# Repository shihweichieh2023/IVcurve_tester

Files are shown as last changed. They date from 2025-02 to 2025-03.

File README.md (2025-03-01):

# I-V Curve Analyzer

A versatile measurement tool for characterizing low-power energy sources, with a focus on Dye-Sensitized Solar Cells (DSSC) and other experimental photovoltaic devices. This open hardware project uses an ESP32-S3 Mini to provide accurate I-V curve measurements and real-time Maximum Power Point tracking.

Originally developed for DIYbio and Hackteria workshops, this analyzer is perfect for:

- Testing Dye-Sensitized Solar Cells (DSSC) with natural dyes
- Characterizing small commercial solar cells
- Evaluating thermoelectric generators (TEGs)
- Educational demonstrations of photovoltaic principles
- Rapid prototyping of new energy harvesting devices

The logarithmic resistor array and optional MOSFET configuration allow measurements across a wide range of power outputs, from µW to mW scale, making it ideal for testing experimental and low-power energy sources.

## Features

- Real-time I-V curve measurement
- Maximum Power Point (MPP) tracking
- ADC (ADS1115) for precise voltage measurements
- OLED display with live readings
- E-ink display for persistent measurements
- Logarithmic resistor array for wide measurement range
- Optional MOSFET for low-resistance measurements
- Optional: Built-in voltage divider for measuring higher voltage sources (>3.3V)

## Button Control
The device features a single button for measurement control:

- OLED display: continously provides real-time measurement data
- Single press: Initiates a new I-V curve measurement to be displayed on the E-ink display and sent to the serial.

## Example I-V Curve
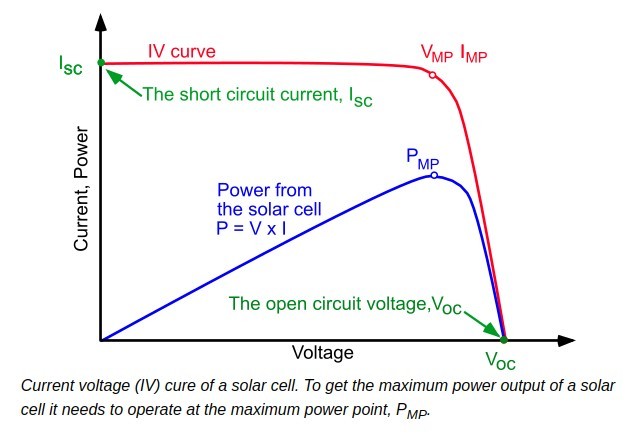
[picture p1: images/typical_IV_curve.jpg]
Typical solar cell I-V curve showing short circuit current (Isc), open circuit voltage (Voc), and Maximum Power Point (MPP)


The analyzer measures both the I-V characteristics (blue curve) and power output (red curve) by sweeping through different load resistances. The Maximum Power Point (MPP) represents the optimal operating point where the product of voltage and current yields the highest power output.

## E-Ink Display Interface
The analyzer features a 2.9" tri-color (black, white, and red) e-ink display (Adafruit IL0373) for persistent measurement visualization. The e-ink display offers:

- High contrast, daylight-readable display
- Persistent display of measurements even when powered off
- 296x128 pixel resolution
- Low power consumption
- E-ink display: Shows the I-V curve with key measurements (Voc, Isc, MPP) 
- The previous measurement is displayed too in lower contrast to compare

The e-ink display provides a persistent view of your latest results that remains visible even when the device is powered off.

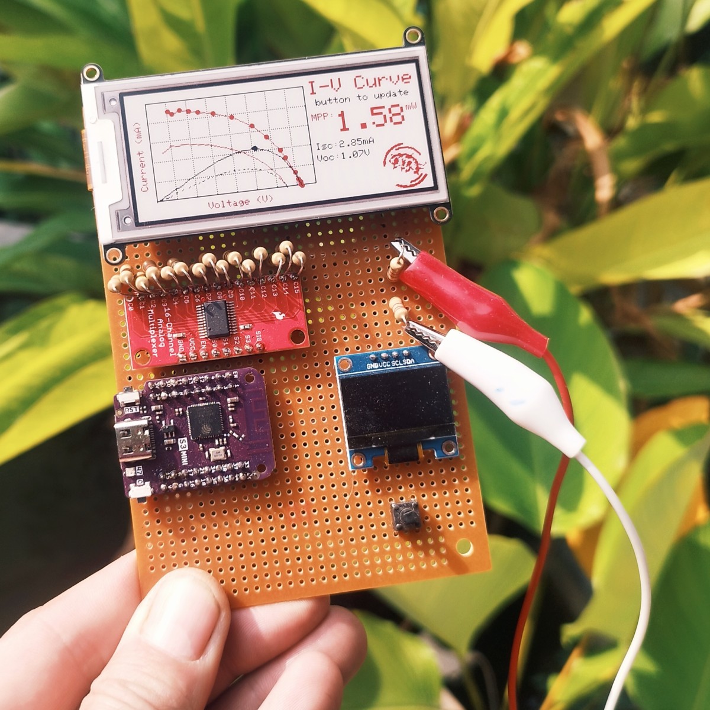
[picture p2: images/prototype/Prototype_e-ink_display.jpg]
E-ink display showing I-V curve measurements

*The e-ink display shows the current measurement in dark contrast while the previous measurement is shown in lighter contrast for easy comparison.*

## Web Interface
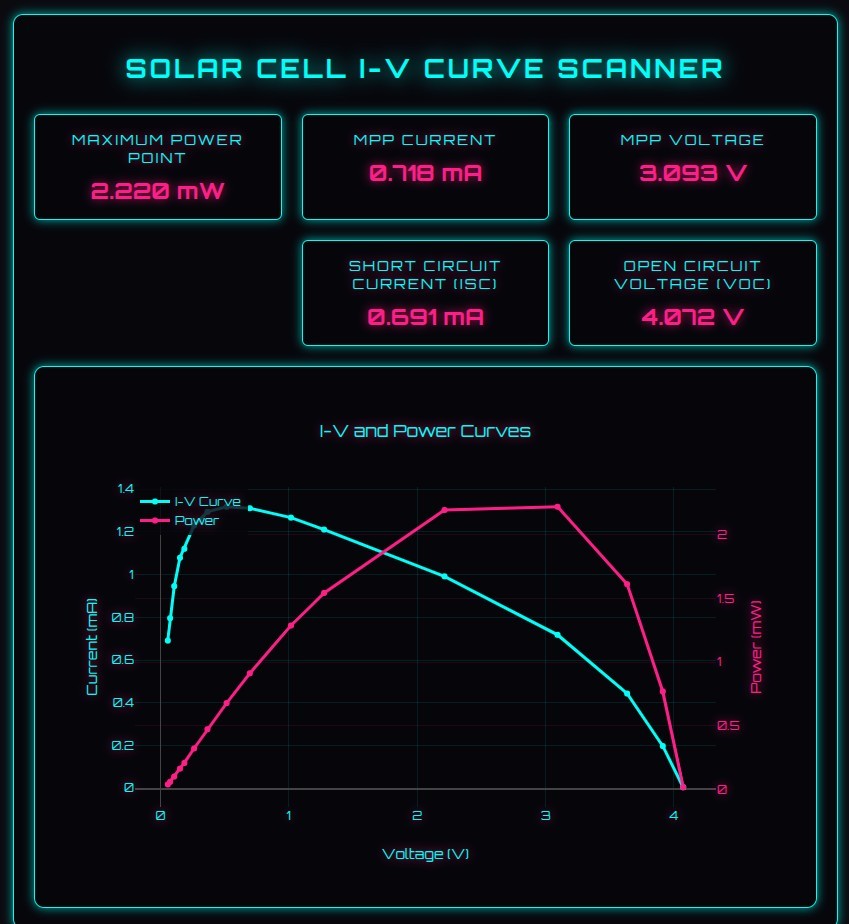
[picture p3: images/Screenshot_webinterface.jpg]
Web interface showing real-time I-V curve and power measurements


The web interface provides real-time visualization of measurements, displaying both the I-V curve (blue) and power curve (pink). Key measurements like Maximum Power Point (MPP), Short Circuit Current (Isc), and Open Circuit Voltage (Voc) are shown in an easy-to-read card layout.

## Hardware Overview
```ascii
+-------------+     +-----------+     +--------------+
|  Solar      |     | ADS1115   |     |  ESP32-S3    |
|  Cell       |---->| ADC (I2C) |---->|    Mini      |
| (DUT)       |     |           |     | (I2C Master) |
+-------------+     +-----------+     +--------------+
       |                                    ^
       |                                    |
       |                                    |
       |                                    |
       |           +---------+              |
       +---------->| MOSFET  |              |
       |           | Circuit |              |
       |           +---------+        +---------------+
       |                |            | UI Controls   |
       |                v            | OLED, Pots,   |
       |               GND           | Button,E-ink  |
       |                             +---------------+
       |
       |
       |            +----------+     +-----------+
       +----------->| Resistor |     |    MUX    |
                    |  Array   |---->|  ADG706   |
                    | (R1-R16) |     | or 4067   |
                    +----------+     +-----------+
                                          |
                                          |
                                          v
                                         GND
```

## Key Components

- ESP32-S3 
- ADG705 16-channel multiplexer
   - or lower precision: CD74HC4067 16-channel multiplexer
- SSD1306 OLED display
- 16 precision resistors (15Ω - 20kΩ)
- MOSFET for low-resistance measurements
- ADS1115 ADC for precision Analog Voltage measurements

## Technical Notes
### Low internal resistance with ADG706 Multiplexer
To be able to measure the currents at high load (low voltages), which completes the curve to the end, a high quality multiplexer is needed, with very low internal resistance. This is the reason why ADG706 was chosen over the CD74HC4067.

#### Resistance Measurement Accuracy with 4067
The CD74HC4067 multiplexer has a significant internal ON resistance (RON) of approximately 70Ω that affects measurements. Rather than compensating for this in software, we've directly measured each resistor through the MUX circuit. The resistor values listed in the code (83Ω - 10.3kΩ) already include this MUX internal resistance, ensuring accurate current calculations without additional compensation.

For example:
 
- A 13Ω resistor + ~70Ω MUX RON = 83Ω actual measured value
- This combined resistance is what's stored in the code
- No additional software compensation needed
- Measurements remain accurate across the full range

### Sensitivity of the ESP32 internal ADC
The ESP32 is known for quite a shitty ADC, non-linear in the middle range, with a very slow slope near the ends. This can cause significant issues with accurate voltage measurements, especially at low voltages.

### Use external ADC, such as ADS1115
Solves the issue.

## Getting Started
1. Clone this repository
2. Install PlatformIO
3. Connect hardware according to [hardware/HARDWARE.md](hardware/HARDWARE.md)
4. Build and upload using PlatformIO

## License
MIT License - See [LICENSE](LICENSE) file

## More Information
See [hardware/HARDWARE.md](hardware/HARDWARE.md) for detailed wiring and setup instructions.

## PCB Design and Prototypes
The project includes a custom PCB design for a MUX ADG706 for more reliable measurements and compact implementation. Design files and documentation can be found in:
 
- Hardware documentation: [`hardware/HARDWARE.md`](hardware/HARDWARE.md)
- PCB design files: [`hardware/MUX-ADG706/`](hardware/MUX-ADG706/)
- PCB renders: [`images/pcb/`](images/pcb/)
- Prototype photos: [`images/prototype/`](images/prototype/)

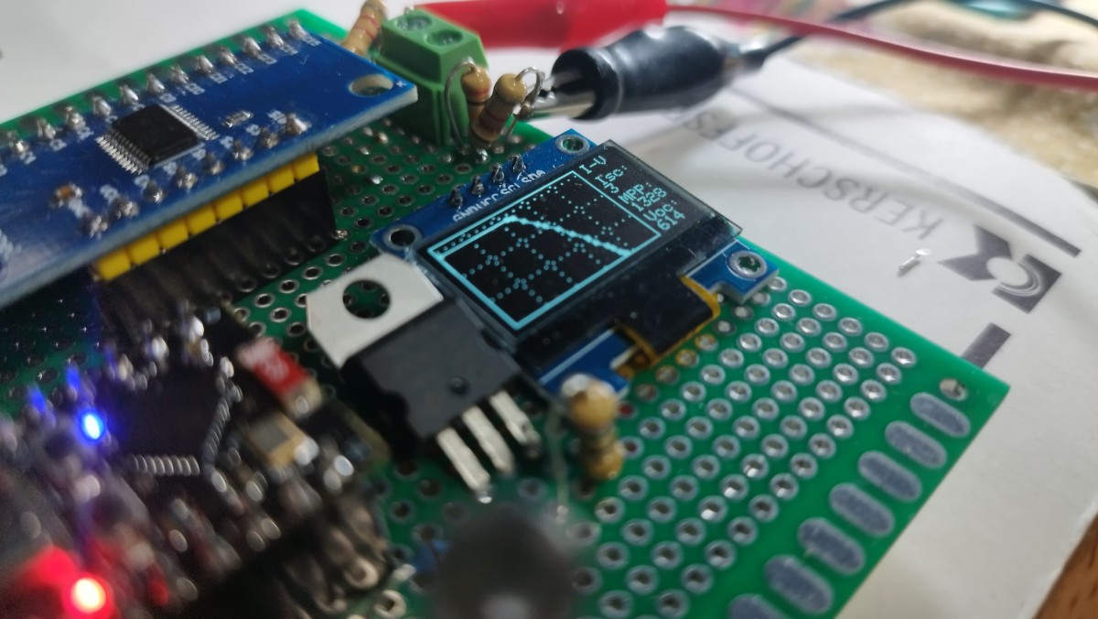
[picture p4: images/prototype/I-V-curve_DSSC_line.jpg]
Prototype measuring DSSC in line

*Close-up view of the analyzer displaying real-time measurements on the OLED screen. The device shows voltage, current, and power readings while performing I-V curve analysis.*

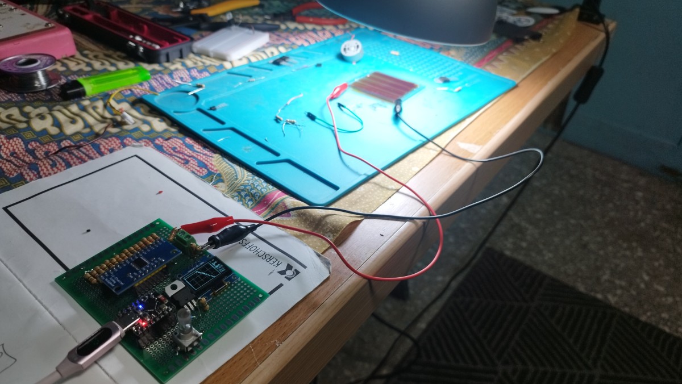
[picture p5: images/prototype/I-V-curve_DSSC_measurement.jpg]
Prototype during DSSC measurement

*First prototype of the I-V Curve Analyzer testing a series of Dye-Sensitized Solar Cells (DSSC). The compact design allows for easy in-line measurements during workshops and experiments.*

### Project Files
The KiCad project (`MUX-ADG706/`) contains:

- [`MUX-ADG706_v2.kicad_sch`](MUX-ADG706/MUX-ADG706_v2.kicad_sch) - Complete circuit schematic
- [`MUX-ADG706_v2.kicad_pcb`](MUX-ADG706/MUX-ADG706_v2.kicad_pcb) - PCB layout design
- [`gerber_MUX-ADG706_v2.zip`](MUX-ADG706/gerber_MUX-ADG706_v2.zip) - Gerber files for PCB manufacturing

## Credits
Code and hardware design by Marc Dusseiller (@dusjagr), with assistance from the Windsurf AI coding assistant. This collaboration demonstrates how AI tools can enhance open hardware development while maintaining human creativity and expertise at the core of the project.

## References
- I-V curve image from [PVEducation.org](https://www.pveducation.org/pvcdrom/solar-cell-operation/iv-curve)

## Future Improvements
Future development plans for the I-V Curve Analyzer include:

1. DONE **Enhanced Multiplexer**: Replace the current multiplexer with ADG706 for lower internal resistance, improving measurement accuracy especially in the low-resistance range.

2. ONGOING **IoT Integration**: Utilize the ESP32's WiFi capabilities to upload measurements to an IoT cloud service for:
   - Remote monitoring and data logging
   - Long-term performance analysis
   - Data sharing and collaboration

3. **On-Board Storage**: Implement measurement storage and numbering on the chip for:
   - Offline data collection
   - Sequential measurement tracking
   - Later retrieval and analysis

These improvements will enhance the device's functionality, usability, and data management capabilities while maintaining its core purpose as an accessible tool for energy harvesting research and education.

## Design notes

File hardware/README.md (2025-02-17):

# Hardware Design Files

This directory contains the hardware design files for the I-V Curve Analyzer project, including detailed assembly instructions and PCB design files.

E-ink display showing I-V curve measurements
*The e-ink display shows the current measurement in dark contrast while the previous measurement is shown in lighter contrast for easy comparison.*

## Directory Structure

- [`HARDWARE.md`](HARDWARE.md) - Detailed assembly instructions and wiring guide
- [`MUX-ADG706/`](MUX-ADG706/) - KiCad project files for the PCB design of the MUX

## PCB Design Overview

The PCB design is implemented in KiCad and features several key improvements over the prototype version:

### Multiplexer Upgrade
The main improvement is the replacement of the CD74HC4067 with the ADG706BRUZ-REEL7 multiplexer:

- Significantly lower ON resistance (~2.5Ω vs 70Ω in the CD74HC4067)
- Better channel-to-channel matching for more consistent measurements
- 28-pin SOP package for compact board layout

### Project Files
The KiCad project (`MUX-ADG706/`) contains:

- [`MUX-ADG706.kicad_sch`](MUX-ADG706/MUX-ADG706.kicad_sch) - Complete circuit schematic
- [`MUX-ADG706.kicad_pcb`](MUX-ADG706/MUX-ADG706.kicad_pcb) - PCB layout design
- [`gerber_MUX-ADG706.zip`](MUX-ADG706/gerber_MUX-ADG706.zip) - Gerber files for PCB manufacturing

### Component Library
The [`ad706/`](MUX-ADG706/ad706/) directory contains all necessary files for the ADG706 multiplexer:

- [`ADG706BRUZ-REEL7.kicad_sym`](MUX-ADG706/ad706/ADG706BRUZ-REEL7.kicad_sym) - KiCad symbol file
- [`SOP65P640X120-28N.kicad_mod`](MUX-ADG706/ad706/SOP65P640X120-28N.kicad_mod) - Footprint for the 28-pin SOP package
- [`ADG706BRUZ-REEL7.step`](MUX-ADG706/ad706/ADG706BRUZ-REEL7.step) - 3D model for visualization

## Design Goals

1. Improve measurement accuracy through lower multiplexer resistance
2. Maintain compact form factor
3. Ensure reliable connections for workshop use
4. Enable precise I-V curve measurements for solar cells and other low-power sources
5. Provide persistent measurement display through e-ink technology

## Display System

The device features a dual-display system:
- **OLED Display**: For real-time measurement data and device status
- **E-ink Display (2.9" Adafruit IL0373)**: For persistent measurement visualization
  - Shows current and previous I-V curves for comparison
  - Maintains display even when powered off
  - High contrast for outdoor readability

## Future Considerations

- Consider adding test points for easier debugging
- Evaluate thermal considerations for continuous operation
- Explore data logging capabilities for long-term studies

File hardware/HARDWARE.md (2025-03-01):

# I-V Curve Analyzer Hardware Documentation
=================================

## Overview
This I-V curve analyzer is designed for characterizing low-power energy sources using either an ESP32-S3 Mini or ESP32-C3 Super Mini board. It uses a multiplexer (CD74HC4067, with planned upgrade to ADG706) to switch between different load resistors and can optionally use a MOSFET for additional low-resistance measurements. A voltage divider is implemented to ensure the input voltage stays within the ESP32's ADC range (0-3.3V), allowing measurement of higher voltage sources while maintaining accuracy.

## Supported Hardware
The firmware supports two board configurations:
1. ESP32-S3 Mini (default)
2. ESP32-C3 Super Mini

To select your board, edit the `include/board_config.h` file and uncomment the appropriate board definition.

## Block Diagram
```ascii
+-------------+     +-----------+     +--------------+
|  Solar      |     | ADS1115   |     |  ESP32-S3    |
|  Cell       |---->| ADC (I2C) |---->|    Mini      |
| (DUT)       |     |           |     | (I2C Master) |
+-------------+     +-----------+     +--------------+
       |                                    ^
       |                                    |
       |                                    |
       |                                    |
       |           +---------+              |
       +---------->| MOSFET  |              |
       |           | Circuit |              |
       |           +---------+        +---------------+
       |                |            | UI Controls   |
       |                v            | OLED, Pots,   |
       |               GND           | Button,E-ink  |
       |                             +---------------+
       |
       |
       |            +----------+     +-----------+
       +----------->| Resistor |     |    MUX    |
                    |  Array   |---->|  ADG706   |
                    | (R1-R16) |     | or 4067   |
                    +----------+     +-----------+
                                          |
                                          |
                                          v
                                         GND
```

## Pin Assignments

### ESP32-S3 Mini
```markdown
# MUX Control
PIN_MUX_S0  (2)  -> MUX control pin S0
PIN_MUX_S1  (6)  -> MUX control pin S1
PIN_MUX_S2  (4)  -> MUX control pin S2
PIN_MUX_S3  (5)  -> MUX control pin S3

# Analog & Digital IO
PIN_SIG     (1)  -> ADC input for voltage measurement
PIN_POT_Y   (16) -> ADC input for Y-axis scaling
PIN_POT_X   (18) -> ADC input for X-axis scaling
PIN_BUTTON  (35) -> Digital input for mode button
PIN_TPI     (10) -> MOSFET control pin

# I2C Interface (OLED & ADS1115)
SDA_PIN     (8)  -> I2C Data
SCL_PIN     (9)  -> I2C Clock

# E-ink Display (SPI)
EPD_DC      (38) -> E-ink DC
EPD_CS      (37) -> E-ink CS
SRAM_CS     (33) -> SRAM CS
EPD_RESET   (10) -> E-ink Reset
SCLK        (12) -> SPI Clock
MISO        (13) -> SPI MISO
MOSI        (11) -> SPI MOSI
```

### ESP32-C3 Super Mini
```markdown
# MUX Control
PIN_MUX_S0  (21) -> MUX control pin S0
PIN_MUX_S1  (10) -> MUX control pin S1
PIN_MUX_S2  (2)  -> MUX control pin S2
PIN_MUX_S3  (1)  -> MUX control pin S3

# Analog & Digital IO
PIN_SIG     (0)  -> ADC input for voltage measurement
PIN_POT_Y   (4)  -> ADC input for Y-axis scaling
PIN_POT_X   (3)  -> ADC input for X-axis scaling
PIN_BUTTON  (7)  -> Digital input for mode button
PIN_TPI     (20) -> MOSFET control pin

# I2C Interface (OLED & ADS1115)
SDA_PIN     (8)  -> I2C Data
SCL_PIN     (9)  -> I2C Clock

# E-ink Display (SPI)
EPD_DC      (5)  -> E-ink DC
EPD_CS      (6)  -> E-ink CS
SRAM_CS     (9)  -> SRAM CS
SCLK        (8)  -> SPI Clock
MISO        (4)  -> SPI MISO
MOSI        (3)  -> SPI MOSI
```

## Components List

- ESP32-S3 Mini development board
- ADG705 16-channel multiplexer
   - or lower precision: CD74HC4067 16-channel multiplexer
- SSD1306 OLED display (128x64)
- Adafruit 2.9" Tri-Color eInk Display FeatherWing (IL0373)
- 16 precision resistors for measurement array
- ADS1115 analog-to-digital converter
- MOSFET circuit for low-resistance measurements
- Push button for measurement control
- Various connectors and headers

## Display Connections

### OLED Display (SSD1306)
- VCC → 3.3V
- GND → GND
- SCL → GPIO22
- SDA → GPIO21

### E-ink Display (IL0373)
- VIN → 3.3V
- GND → GND
- SCK → GPIO36
- MOSI → GPIO35
- DC → GPIO37
- CS → GPIO38
- RST → GPIO39
- BUSY → GPIO40

## Detailed Connections
### CD74HC4067 Multiplexer
```ascii
      +-----U-----+
CH7   |1  []   24| VCC
CH6   |2       23| CH8
CH5   |3       22| CH9
CH4   |4       21| CH10
CH3   |5       20| CH11
CH2   |6       19| CH12
CH1   |7       18| CH13
CH0   |8       17| CH14
COM   |9       16| CH15
S0    |10      15| EN
S1    |11      14| S2
GND   |12      13| S3
      +-----------+
```

### ADS1115 Analog-to-Digital Converter
- VCC → 3.3V
- GND → GND
- SDA → GPIO8  (I2C Data)
- SCL → GPIO9  (I2C Clock)
- A0  → Positiv Voltage of the panel for measurement

### Resistor Array
Connected to MUX channels, values in ohms:
```markdown
R1  ->  10317Ω
R2  ->   6856Ω
R3  ->   4723Ω
R4  ->   3211Ω
R5  ->   1878Ω
R6  ->    972Ω
R7  ->    764Ω
R8  ->    516Ω
R9  ->    383Ω
R10 ->    278Ω
R11 ->    212Ω
R12 ->    165Ω
R13 ->    142Ω
R14 ->    114Ω
R15 ->     95Ω
R16 ->     83Ω
```

### MOSFET Circuit Configuration
```ascii
Solar Cell+
    |
    |------------+----------------+
    |            |                |
    |         Resistor         MOSFET
    |           Array        +-------+
    |            |           |Gate   |
    |            |           |       |<----GPIO8 (TPI)
    |            v           |       |      |
    |           MUX          |Drain  |      |
    |            |           |       |      |
    |            |           |Source |      |
    |            |           +-------+      |
    |            |               |          |
    |            |               |          |
    +------------+---------------+----------+
                                 |
                                GND
```

## Connection Details

### Solar Cell / Device Under Test (DUT)
- **Positive Terminal**: 
  - Connects to all resistors (R1-R16) in parallel
  - Connects to MOSFET drain
- **Negative Terminal**: 
  - Connects to MUX COM pin (9)
  - Connects to MOSFET source

### Power Supply
- ESP32-S3 Mini is powered via USB (5V)
- Solar cell or DUT is only connected to measurement inputs

## Operating Modes

### Current Implementation
- Uses resistor array only (R1-R16)
- MOSFET kept OFF (GPIO8 = LOW)
- Measures through each resistor sequentially

### Future Enhancement: MOSFET Integration
Can operate in three modes:
1. MOSFET only (very low resistance when ON)
2. Resistor only (R1-R16 through MUX)
3. MOSFET + Resistor in parallel (for intermediate values)

This would triple the measurement points, particularly useful in the low-resistance region where maximum power often occurs.

## Safety Considerations

### Voltage Protection
1. Maximum input voltage should not exceed 3.3V
2. Use voltage dividers if input might exceed 3.3V
3. Add protection diodes for unknown voltage sources

### General Safety
1. Keep all grounds connected
2. Add bypass capacitors near ICs
3. Use appropriate power ratings for resistors
4. Consider MOSFET heat dissipation during parallel operation

## Measurement Process
1. Cycles through resistors R1-R16
2. Measures voltage across each load
3. Calculates current using measured resistance values
4. Computes power and identifies Maximum Power Point (MPP)
5. Displays results on OLED:
   - Maximum Power (mW)
   - Voltage at MPP (mV)
   - Current at MPP (µA)

## Notes
- Resistor values shown are actual measured values through MUX
- Values form roughly logarithmic progression
- MOSFET circuit is prepared for future enhancements
- Button press triggers detailed serial output
- Display updates in real-time with measurements

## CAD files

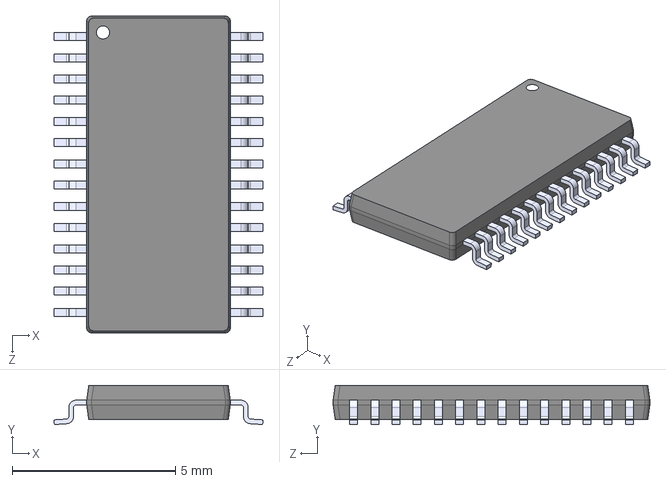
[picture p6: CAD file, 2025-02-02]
hardware/MUX-ADG706/ad706/ADG706BRUZ-REEL7.step
6.40 x 1.20 x 9.70 mm

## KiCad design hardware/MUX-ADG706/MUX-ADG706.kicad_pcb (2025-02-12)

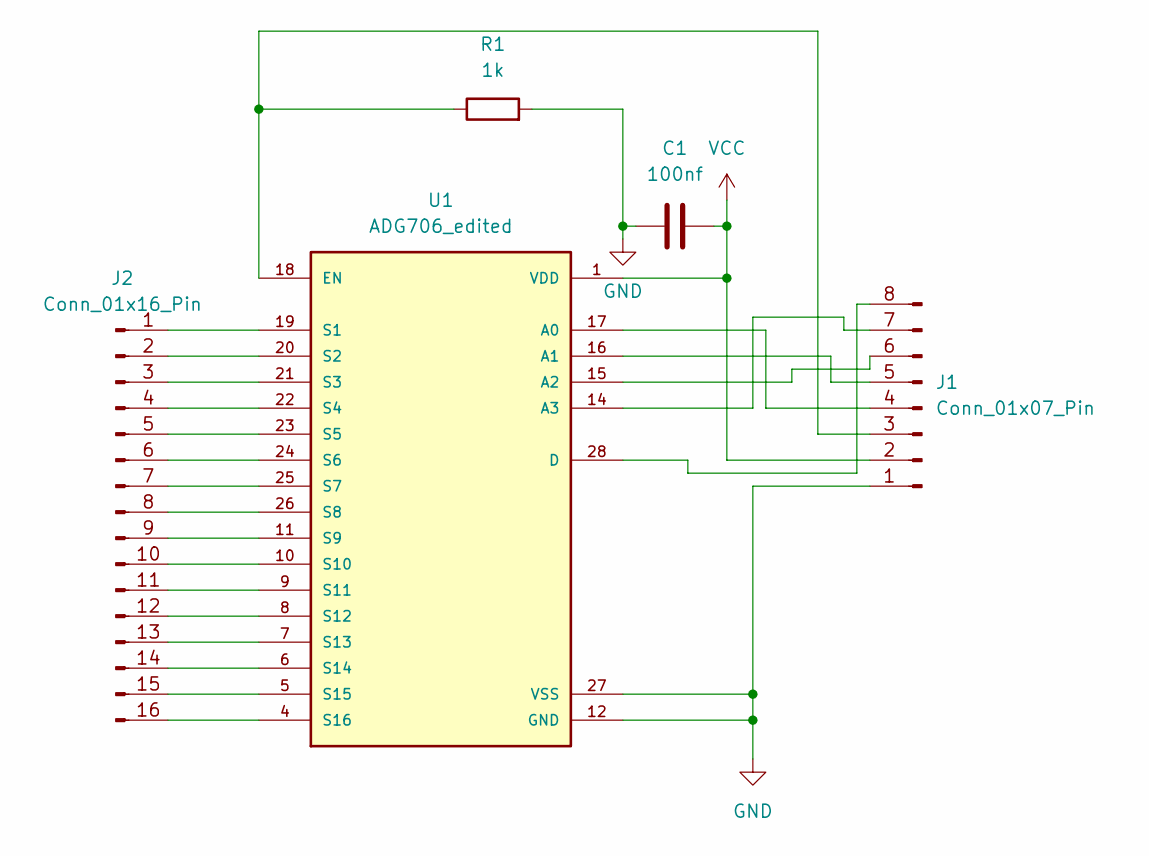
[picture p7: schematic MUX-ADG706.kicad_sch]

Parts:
C1: 100nf; C_1210_noGND
J1: Conn_01x07_Pin; PinHeader_1x08_P2.54mm_bigPads
J2: Conn_01x16_Pin; PinHeader_1x16_P2.54mm_bigPads
R1: 1k; R_1206_noGND
U1: ADG706_edited; ADG704-28N

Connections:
GND: C1.1, J1.1, R1.2, U1.12 (GND), U1.27 (VSS)
unnamed: J1.3, R1.1, U1.18 (EN)
unnamed: J1.4, U1.17 (A0)
unnamed: J1.5, U1.16 (A1)
unnamed: J1.6, U1.15 (A2)
unnamed: J1.7, U1.14 (A3)
unnamed: J1.8, U1.28 (D)
unnamed: J2.16 (9), U1.4 (S16)
unnamed: J2.1, U1.19 (S1)
unnamed: J2.2, U1.20 (S2)
unnamed: J2.3, U1.21 (S3)
unnamed: J2.4, U1.22 (S4)
unnamed: J2.5, U1.23 (S5)
unnamed: J2.6, U1.24 (S6)
unnamed: J2.7, U1.25 (S7)
unnamed: J2.8, U1.26 (S8)
unnamed: J2.9, U1.11 (S9)
unnamed: J2.10, U1.10 (S10)
unnamed: J2.11, U1.9 (S11)
unnamed: J2.12, U1.8 (S12)
unnamed: J2.13, U1.7 (S13)
unnamed: J2.14, U1.6 (S14)
unnamed: J2.15, U1.5 (S15)
VCC: C1.2, J1.2, U1.1 (VDD)

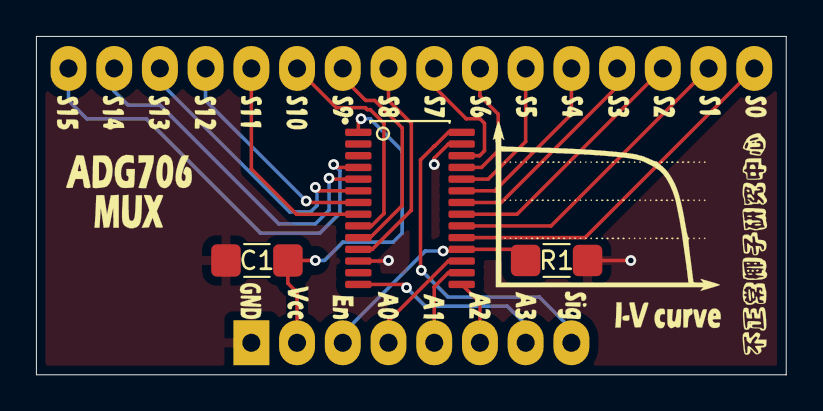
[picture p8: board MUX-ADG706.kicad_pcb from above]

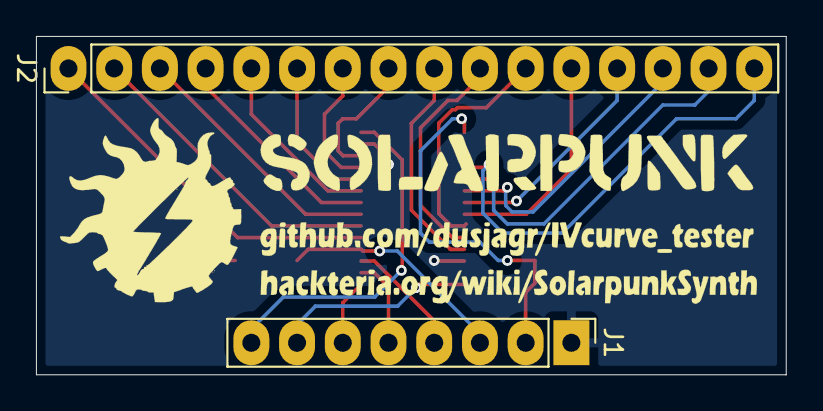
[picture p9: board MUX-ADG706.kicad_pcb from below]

Board: 2 copper layers, 41.7 x 18.8 mm, 7 parts (2 on the bottom side), 24 nets.

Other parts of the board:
Ref**: Val**; Back_silkscreen
Ref**#2: Val**; silkscreen

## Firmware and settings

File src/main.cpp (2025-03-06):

/*
I-V curve analyzer for low-power energies
Array of resistors and MUX through 15 of them, and 1 open circuit
Display on OLED screen.

Features:
* Real-time I-V curve display with adjustable scaling
* Maximum Power Point (MPP) tracking
* Maximum current and voltage measurements
* Interactive display with button control
* Serial data output mode

Hardware Setup:
* ESP32-S3 Mini board
* SSD1306 OLED display (128x64)
* 4051 Multiplexer for resistor array
* Two potentiometers for X/Y scaling
* Button for serial mode toggle
*/

#include <SPI.h>
#include <Wire.h>
#include <Adafruit_GFX.h>
#include <Adafruit_SSD1306.h>
#include "Adafruit_ThinkInk.h"
#include "hackteria_logo.h"
#include <WiFi.h>
#include <WebServer.h>
#include <ESPmDNS.h>
#include "config.h"
#include "board_config.h"
#include "IVserver.h"
#include <Adafruit_ADS1X15.h>
#include "ThingSpeak.h"
#include <ArduinoJson.h>
#include <Adafruit_NeoPixel.h>

// Display Configuration
#define SCREEN_WIDTH 128 // OLED display width, in pixels
#define SCREEN_HEIGHT 64 // OLED display height, in pixels
#define SCREEN_ADDRESS 0x3C // OLED display I2C address

// Declaration for displays
Adafruit_SSD1306 oled(SCREEN_WIDTH, SCREEN_HEIGHT, &Wire);
ThinkInk_290_Tricolor_Z10 eink(EPD_DC, EPD_RESET, EPD_CS, SRAM_CS, EPD_BUSY, &SPI);
Adafruit_ADS1115 ads;  // Create an ADS1115 instance

// Global IV Server instance
//IVserver server(80);  // Create an IV server on port 80

// ThingSpeak client
WiFiClient client;

// Define LED states
#define LED_IDLE      0  // Blue
#define LED_MEASURING 1  // Yellow
#define LED_SENDING   2  // Purple
#define LED_SUCCESS   3  // Green
#define LED_ERROR     4  // Red

// Initialize NeoPixel
Adafruit_NeoPixel pixel(1, PIN_RGBLED, NEO_RGB + NEO_KHZ800);

// Function declarations
void initOLED();
void initEink();
void drawOnEink();
void drawOnEinkBackground();
void drawBackground();
void drawIVline();
void showLogo_hackteria();
void showBootScreen();
void showCreditsScreen();
void setupNetwork();
void handleIVserver();
void setupIVserver();
int readMux(int channel);
void printMeasurements();
void drawDashedLine(int x0, int y0, int x1, int y1, uint16_t color, int dashLength, int gapLength);
void setupThingSpeak();
void sendToThingSpeak(float voc, float isc, float mpp, float ff);
void setupLED();
void setLEDState(uint8_t state);

// Pin assignments from board configuration
int s0 = PIN_MUX_S0;      // MUX control pin S0
int s1 = PIN_MUX_S1;      // MUX control pin S1
int s2 = PIN_MUX_S2;      // MUX control pin S2
int s3 = PIN_MUX_S3;      // MUX control pin S3
int SIG_pin = PIN_SIG;    // ADC input for voltage measurement
int POTY_pin = PIN_POT_Y; // ADC input for Y-axis scaling
int POTX_pin = PIN_POT_X; // ADC input for X-axis scaling
int BUTT_pin = PIN_BUTTON;// Digital input for mode button
int TPI_pin = PIN_TPI;    // Test Point Input control

// Hardware Variables
#ifdef MUX_ADG706
const int resistorCorrection = 64;  // Correction Value for ADG706
#endif
#ifdef MUX_4051
const int resistorCorrection = 25;  // For old Mux
#endif

// Measurement and display variables
int overlay = 0; // Display overlay state
int scaleY;      // Y-axis (current) scaling factor from potentiometer
int scaleX;      // X-axis (voltage) scaling factor from potentiometer
const int average = 1;           // Number of readings to average
const int delayLoop = 10;        // Main loop delay
const int delayAveraging = 4;    // Delay between ADC readings for averaging
const int delayMuxSwitch = 2;    // Delay after MUX switching for voltage stabilization
const int delayWebUpdate = 2000;  // Web server update delay in milliseconds

// Interface Control Variables
bool serialMode = 0;          // Serial output mode flag
bool buttonState = false;     // Current button state
bool lastButtonState = false; // Previous button state
unsigned long lastPressTime = 0;      // Last button press timestamp
const unsigned long recentThreshold = 2000; // Button press timeout (ms)

// Global Measurement Variables
float vocValues[20];   // Array to store voltage measurements
float icalValues[20];  // Array to store calculated currents
float powValues[20];   // Array to store power values
float prevVocValues[20];   // Array to store previous voltage measurements
float prevIcalValues[20];  // Array to store previous current measurements
float prevPowValues[20];   // Array to store previous power values
float maxPower = 0;    // Maximum power point tracking
float maxCurrent = 0;  // Maximum current tracking
float maxVoltage = 0;  // Maximum voltage tracking
float prevMaxPower = 0;    // Previous maximum power
float prevMaxCurrent = 0;  // Previous maximum current
float prevMaxVoltage = 0;  // Previous maximum voltage
bool hasPreviousMeasurement = false;  // Flag to track if we have a previous measurement
int mppIndex = 0;      // Index of maximum power point
int prevMppIndex = 0;  // Previous maximum power point index

// Resistor array values in ohms (measured through MUX)
int resistorValues[20]{
  1000000,
  19910,
  8200,
  4310,
  2230,
  1052,
  802,
  530,
  390,
  282,
  212,
  165,
  141,
  113,
  93,
  81,
  81,
  81,
  81,
  81
};

// Add global variable for button press detection
volatile bool buttonPressed = false;

void setup() {
  Serial.begin(115200);
  delay(500);  // Give more time for Serial to initialize
  //while (!Serial) { delay(10); }  // Wait for Serial to be ready
  Serial.println("=========== Initializing I-V Scanner ===========");
  Serial.println("");
  delay(100);

  // Initialize MUX control pins
  pinMode(s0, OUTPUT);
  pinMode(s1, OUTPUT);
  pinMode(s2, OUTPUT);
  pinMode(s3, OUTPUT);  // Added s3 pin initialization
  pinMode(PIN_BUTTON, INPUT_PULLUP);
  
  // Initialize arrays to zero
  memset(vocValues, 0, sizeof(vocValues));
  memset(icalValues, 0, sizeof(icalValues));
  memset(powValues, 0, sizeof(powValues));
  memset(prevVocValues, 0, sizeof(prevVocValues));
  memset(prevIcalValues, 0, sizeof(prevIcalValues));
  memset(prevPowValues, 0, sizeof(prevPowValues));
  
  // Initialize OLED
  initOLED();

  // Initialize ADS1115
  #ifdef hasADS1115
  ads.begin(0x48);
  ads.setGain(GAIN_ONE);    // 1x gain   +/- 4.096V  1 bit = 0.125mV
  #endif

  // Initialize NeoPixel
  setupLED();
  setLEDState(LED_IDLE);

  // Show logo
  showLogo_hackteria();
  delay(1000);
  
  Serial.println("");
  Serial.println("=========== Connecting to Wi-fi ===========");

  // Initialize network and server
  setupNetwork();
  if (WiFi.status() == WL_CONNECTED) {
    setupIVserver();
    setupThingSpeak();
  }
  
  Serial.println("");
  Serial.println("=========== IV Server started ===========");
  Serial.println("");

  // Show bootscreen
  showBootScreen();
  delay(10);

  // Initialize E-ink
  #ifdef hasEink
  initEink();
  #endif
  
  // Show credits screen
  showCreditsScreen();
  delay(1000);
  
  Serial.println("");
  Serial.println("=========== Starting I-V Scanner ===========");
  Serial.println("");

  // Clear display and draw background
  oled.clearDisplay();
  drawBackground();
  oled.display();
}

void loop() {
  // Handle IV server requests
  if (WiFi.status() == WL_CONNECTED) {
    handleIVserver();
  }
  
  // Read scaling potentiometers
  scaleX = analogReadMilliVolts(POTX_pin);
  scaleY = analogReadMilliVolts(POTY_pin);
  digitalWrite(TPI_pin, 0);
  
  // Take continuous measurements
  digitalWrite(s0, 0);
  digitalWrite(s1, 0);
  digitalWrite(s2, 0);
  digitalWrite(s3, 0);
  digitalWrite(TPI_pin, 0);
  delay(50);

  // Reset max values for new measurement
  maxPower = 0;
  maxCurrent = 0;
  maxVoltage = 0;
  mppIndex = 0;

  // Complete full measurement cycle
  #ifdef BOARD_ESP32S3_MINI
  for (int i = 0; i < 16; i++) {
    vocValues[i] = readMux(i);  // Get voltage directly from return value
    icalValues[i] = vocValues[i] / (resistorValues[i] - resistorCorrection);  // Calculate current in mA
    powValues[i] = vocValues[i] * icalValues[i];  // Calculate power
    
    // Update maximum values
    if (powValues[i] > maxPower) {
      maxPower = powValues[i];
      mppIndex = i;
    }
    
    // Find absolute maximum current and voltage
    if (icalValues[i] > maxCurrent) {
      maxCurrent = icalValues[i];
    }
    if (vocValues[i] > maxVoltage) {
      maxVoltage = vocValues[i];
    }
    
    delay(delayAveraging);
  }
  #endif

#ifdef BOARD_ESP32C3_SUPER_MINI
  for (int i = 0; i < 14; i++) {
    vocValues[i] = readMux(i);  // Get voltage directly from return value
    icalValues[i] = vocValues[i] / (resistorValues[i] - resistorCorrection);  // Calculate current in mA
    powValues[i] = vocValues[i] * icalValues[i];  // Calculate power
    
    // Update maximum values
    if (powValues[i] > maxPower) {
      maxPower = powValues[i];
      mppIndex = i;
    }
    
    // Find absolute maximum current and voltage
    if (icalValues[i] > maxCurrent) {
      maxCurrent = icalValues[i];
    }
    if (vocValues[i] > maxVoltage) {
      maxVoltage = vocValues[i];
    }
    
    delay(delayAveraging);
  }
#endif

  // Update IV server with new measurement data
  static unsigned long lastWebUpdate = 0;
  if (millis() - lastWebUpdate >= delayWebUpdate) {
    IVData data;
    data.maxPower = maxPower;
    data.maxCurrent = icalValues[mppIndex];  // Use current at MPP
    data.maxVoltage = vocValues[mppIndex];   // Use voltage at MPP
    data.numPoints = 16;
    
    // Copy array values
    for(int i = 0; i < 16; i++) {
      data.vocValues[i] = vocValues[i];
      data.icalValues[i] = icalValues[i];
      data.powValues[i] = powValues[i];
    }
    if (WiFi.status() == WL_CONNECTED) {
      updateIVserverData(data);
    }
    lastWebUpdate = millis();
  }
  
  // Update OLED display continuously
  drawIVline();

  // Handle button press
  if (buttonPressed) {
    setLEDState(LED_MEASURING);
    Serial.println("Button pressed!");
    
    // First draw the e-ink display with current measurement in red and previous in black
    #ifdef hasEink
    drawOnEink();
    #endif
    printMeasurements();
    
    // Only after displaying, store current as previous for next time
    memcpy(prevVocValues, vocValues, sizeof(vocValues));
    memcpy(prevIcalValues, icalValues, sizeof(icalValues));
    memcpy(prevPowValues, powValues, sizeof(powValues));
    prevMaxPower = maxPower;
    prevMaxCurrent = maxCurrent;
    prevMaxVoltage = maxVoltage;
    prevMppIndex = mppIndex;
    hasPreviousMeasurement = true;

    // Send data to ThingSpeak if WiFi is connected
    if (WiFi.status() == WL_CONNECTED) {
      setLEDState(LED_SENDING);
      // Calculate values to send
      float voc = vocValues[0];          // Open circuit voltage in mV
      float isc = icalValues[15];        // Short circuit current in mA
      float mpp = maxPower;              // Maximum power in mW
      float ff = (maxPower / ((vocValues[0]/1000.0) * icalValues[15])) / 10;  // Fill factor (already calculated)
      
      // Send to ThingSpeak (values already in correct units)
      sendToThingSpeak(voc, isc, mpp, ff);
      setLEDState(LED_SUCCESS);
      delay(1000);  // Show success for 1 second
    } else {
      setLEDState(LED_ERROR);
      delay(1000);  // Show error for 1 second
    }
    
    setLEDState(LED_IDLE);
    buttonPressed = false;  // Reset flag
    delay(200);  // Debounce delay
  }
  
  delay(delayLoop);
}

int readMux(int channel) {
  int sig = 0;
  float multiplier = 0.125F; // 4.096V range = 0.125mV per bit
  int16_t adc0;
  
  // Set the channel on MUX
  digitalWrite(s0, bitRead(channel, 0));
  digitalWrite(s1, bitRead(channel, 1));
  digitalWrite(s2, bitRead(channel, 2));
  digitalWrite(s3, bitRead(channel, 3));
  delay(delayMuxSwitch);  // Delay for voltage stabilization after switching
  
  // Take multiple readings and average
  for(int i = 0; i < average; i++) {
    // Check for button press during measurement
    if (digitalRead(PIN_BUTTON) == LOW) {  // Button pressed
      buttonPressed = true;
    }


    #ifdef hasADS1115
    adc0 = ads.readADC_SingleEnded(0);
    sig += adc0 * multiplier; // read from ADC1115
    #endif
    #ifdef hasESPADC
    sig += analogReadMilliVolts(SIG_pin);  // Multiply by 2 to account for voltage divider
    #endif
    
    delay(delayAveraging);
  }
  
  return sig / average;
}

void printMeasurements() {
  Serial.println("    ");
  Serial.println("=========== I calculated ===========");
  for(int i = 0; i < 16; i ++){
    Serial.println(icalValues[i]);
  }

  Serial.println("=========== Power calculated ===========");
  for(int i = 0; i < 16; i ++){
    Serial.println(powValues[i]);
  }
  Serial.println("    ");
  Serial.println("=========== V meas===========");
  for(int i = 0; i < 16; i ++){
    Serial.println(vocValues[i]);
  }  

  Serial.println("=========== MPP ===========");
  Serial.print("MPP Index: ");
  Serial.println(mppIndex);
  Serial.print("Voltage at MPP: ");
  Serial.print(vocValues[mppIndex]);
  Serial.println(" mV");
  Serial.print("Current at MPP: ");
  Serial.print(icalValues[mppIndex]);
  Serial.println(" mA");
  Serial.print("Power at MPP: ");
  Serial.print(powValues[mppIndex]);
  Serial.println(" uW");
  Serial.println("=========== DONE ===========");
  delay(10);
}

void initOLED() {
  // Initialize OLED with I2C
  Serial.println("Initializing OLED display");
  Wire.begin(SDA_PIN, SCL_PIN);
  if(!oled.begin(SSD1306_SWITCHCAPVCC, SCREEN_ADDRESS, false, false)) {
    Serial.println(F("SSD1306 allocation failed"));
    for(;;);  // Don't proceed, loop forever
  }
  oled.clearDisplay();
  oled.display();
  delay(50);
  Serial.println("OLED display initialized");
}

void initEink() {
  // Initialize E-ink with proper delays
  Serial.println("Initializing e-ink display");
  delay(100);
  eink.begin(THINKINK_TRICOLOR);
  delay(100);
  
  // Clear the buffer
  eink.clearBuffer();
  
  // Draw the initial background (grid and labels only)
  drawOnEinkBackground();
  
  Serial.println("E-ink display initialized");
}

void drawOnEink() {
  eink.powerUp();    // Power up the display
  delay(100);        // Wait for power up
  
  eink.clearBuffer();
  delay(50);         // Wait after clear
  
  // Draw frame for I-V curve (160x100 pixels)
  eink.drawRect(20, 10, 160, 100, EPD_BLACK);
  
  // Draw grid lines - vertical (8 sections of 20 pixels each)
  for (int i = 0; i < 160; i += 20) {  
    for (int j = 10; j < 110; j += 2) {   
      if (i > 0) eink.drawPixel(i + 20, j, EPD_BLACK);  
    }
  }
  
  // Draw grid lines - horizontal (10 sections)
  for (int i = 0; i < 100; i += 20) {    
    for (int j = 20; j < 180; j += 2) {  
      if (i > 0) eink.drawPixel(j, i + 10, EPD_BLACK);  
    }
  }

  // Draw X-axis label with proper rotation
  eink.setTextSize(1);
  eink.setTextColor(EPD_RED);
  eink.setCursor(70, 116);
  eink.print("Voltage (V)");
  
  // Draw Y-axis label with proper rotation
  uint8_t oldRotation = eink.getRotation();
  eink.setRotation(3);  
  eink.setCursor(30, 6);  
  eink.print("Current (mA)");
  eink.setRotation(oldRotation);  
  
  // Calculate scaling factors ONCE using max values from both measurements
  float scaleX_auto = 160.0 / (max(maxVoltage, hasPreviousMeasurement ? prevMaxVoltage : 0) * 1.1);  
  float scaleY_auto = 100.0 / (max(maxCurrent, hasPreviousMeasurement ? prevMaxCurrent : 0) * 1.1);   
  float scaleY_power = 47.5 / (max(maxPower, hasPreviousMeasurement ? prevMaxPower : 0) * 1.1);    
  
  // Calculate maximum values for axis labels
  float maxVoltage = 160.0 / scaleX_auto;  // 160 pixels is full scale X
  float maxCurrent = 100.0 / scaleY_auto;  // 100 pixels is full scale Y
  
  // Format the values with 2 decimal places
  char voltageStr[10];
  char currentStr[10];
  snprintf(voltageStr, sizeof(voltageStr), "%.1fV", maxVoltage/1000);  // Format voltage with unit
  snprintf(currentStr, sizeof(currentStr), "%.1fmA", maxCurrent);  // Convert to mA and format with 2 decimals
  
  // Draw axis max values
  eink.setTextSize(1);
  eink.setTextColor(EPD_BLACK);
  
  // Voltage max value (X-axis) - at the end of X axis
  eink.setCursor(170, 116);  // Position just right of the graph, aligned with axis
  eink.print(voltageStr);
  
  // Current max value (Y-axis) - at the top of Y axis
  eink.setCursor(8, 2);  // Position just left of the graph, aligned with top
  eink.print(currentStr);
  
  // Only plot previous measurement if we have one
  if (hasPreviousMeasurement) {
    // First draw the previous measurement in red (without dots)
    for(int i = 0; i < 16; i++) {
      int x = 20 + (int)(prevVocValues[i] * scaleX_auto);
      int y = 110 - (int)(prevIcalValues[i] * scaleY_auto);
      x = constrain(x, 20, 180);
      y = constrain(y, 10, 110);
      if (i == 0) {
        eink.drawPixel(x, y, EPD_RED);
      } else {
        int x_prev = 20 + (int)(prevVocValues[i-1] * scaleX_auto);
        int y_prev = 110 - (int)(prevIcalValues[i-1] * scaleY_auto);
        x_prev = constrain(x_prev, 20, 180);
        y_prev = constrain(y_prev, 10, 110);
        eink.drawLine(x_prev, y_prev, x, y, EPD_RED);
      }
    }
  }

  // Then plot the current measurement in red with dots
  for(int i = 0; i < 16; i++) {
    int x = 20 + (int)(vocValues[i] * scaleX_auto);
    int y = 110 - (int)(icalValues[i] * scaleY_auto);
    x = constrain(x, 20, 180);
    y = constrain(y, 10, 110);
    if (i == 0) {
      eink.drawPixel(x, y, EPD_RED);
    } else {
      int x_prev = 20 + (int)(vocValues[i-1] * scaleX_auto);
      int y_prev = 110 - (int)(icalValues[i-1] * scaleY_auto);
      x_prev = constrain(x_prev, 20, 180);
      y_prev = constrain(y_prev, 10, 110);
      eink.drawLine(x_prev, y_prev, x, y, EPD_RED);
    }
    // Add dots at each measurement point
    eink.fillCircle(x, y, 2, EPD_RED);
  }

  // Add MPP dot on the I-V curve (current measurement)
  if (maxPower > 0 && mppIndex >= 0 && mppIndex < 16) {
    int mpx = 20 + (int)(vocValues[mppIndex] * scaleX_auto);
    int mpy = 110 - (int)(icalValues[mppIndex] * scaleY_auto);
    mpx = constrain(mpx, 20, 180);
    mpy = constrain(mpy, 10, 110);
    eink.fillCircle(mpx, mpy, 4, EPD_RED);  
  }
  
  // Draw previous power curve in black
  if (hasPreviousMeasurement) {
    // Draw from high V to low V (index 0 to 15)
    for(int i = 15; i > 0; i--) {  
      float prev_power1 = prevVocValues[i] * prevIcalValues[i];
      float prev_power2 = prevVocValues[i-1] * prevIcalValues[i-1];
      
      int x1 = 20 + (int)(prevVocValues[i] * scaleX_auto);
      int y1 = 110 - (int)(prev_power1 * scaleY_power);
      int x2 = 20 + (int)(prevVocValues[i-1] * scaleX_auto);
      int y2 = 110 - (int)(prev_power2 * scaleY_power);
      
      x1 = constrain(x1, 20, 180);
      y1 = constrain(y1, 10, 110);
      x2 = constrain(x2, 20, 180);
      y2 = constrain(y2, 10, 110);
      
      drawDashedLine(x1, y1, x2, y2, EPD_BLACK, 2, 2);  
    }
    
    // Connect lowest V point (index 15) to origin for previous curve
    float prev_last_power = prevVocValues[15] * prevIcalValues[15];
    int x1 = 20 + (int)(prevVocValues[15] * scaleX_auto);
    int y1 = 110 - (int)(prev_last_power * scaleY_power);
    x1 = constrain(x1, 20, 180);
    y1 = constrain(y1, 10, 110);
    drawDashedLine(x1, y1, 20, 110, EPD_BLACK, 2, 2);  
  }

  // Draw power curve (current measurement in black)
  // Draw from high V to low V (index 0 to 15)
  for(int i = 15; i > 0; i--) {  
    float power1 = vocValues[i] * icalValues[i];
    float power2 = vocValues[i-1] * icalValues[i-1];
    
    int x1 = 20 + (int)(vocValues[i] * scaleX_auto);
    int y1 = 110 - (int)(power1 * scaleY_power);
    int x2 = 20 + (int)(vocValues[i-1] * scaleX_auto);
    int y2 = 110 - (int)(power2 * scaleY_power);
    
    x1 = constrain(x1, 20, 180);
    y1 = constrain(y1, 10, 110);
    x2 = constrain(x2, 20, 180);
    y2 = constrain(y2, 10, 110);
    
    eink.drawLine(x1, y1, x2, y2, EPD_BLACK);  
  }

  // Connect lowest V point (index 15) to origin for current curve
  float last_power = vocValues[15] * icalValues[15];
  int x1 = 20 + (int)(vocValues[15] * scaleX_auto);
  int y1 = 110 - (int)(last_power * scaleY_power);
  x1 = constrain(x1, 20, 180);
  y1 = constrain(y1, 10, 110);
  eink.drawLine(x1, y1, 20, 110, EPD_BLACK);
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

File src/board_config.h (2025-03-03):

#ifndef BOARD_CONFIG_H
#define BOARD_CONFIG_H

// Choose your board by uncommenting one of these:
#define BOARD_ESP32S3_MINI
//#define BOARD_ESP32C3_SUPER_MINI

// Choose which MUX is used
#define MUX_ADG706
//#define MUX_4051

// Choose which ADC is used
#define hasADS1115
//#define hasESPADC

// Does the system has the E-ink display?
#define hasEink

#ifdef BOARD_ESP32S3_MINI
    #define PIN_MUX_S0      2   // MUX control pin S0
    #define PIN_MUX_S1      6   // MUX control pin S1
    #define PIN_MUX_S2      4   // MUX control pin S2
    #define PIN_MUX_S3      5   // MUX control pin S3
    #define PIN_SIG         1   // ADC input for voltage measurement
    #define PIN_POT_Y       16  // ADC input for Y-axis scaling
    #define PIN_POT_X       18  // ADC input for X-axis scaling
    #define PIN_BUTTON      35  // Digital input for mode button
    #define PIN_TPI         10  // Test Point Input control
    #define PIN_RGBLED      47  // RGB LED control pin

    // I2C Pin Definitions
    #define SDA_PIN 8   // Default I2C SDA for S3-Mini
    #define SCL_PIN 9   // Default I2C SCL for S3-Mini
    
    // E-ink display pins
    #define EPD_DC      38
    #define EPD_CS      37
    #define SRAM_CS     33  
    #define EPD_RESET   10
    #define EPD_BUSY    -1

    // SPI Pins for E-ink
    #define SCLK        12
    #define MISO        13
    #define MOSI        11
#endif

#ifdef BOARD_ESP32C3_SUPER_MINI
    #define PIN_MUX_S0      21  // MUX control pin S0
    #define PIN_MUX_S1      10  // MUX control pin S1
    #define PIN_MUX_S2      2   // MUX control pin S2
    #define PIN_MUX_S3      1   // MUX control pin S3
    #define PIN_SIG         0   // ADC input for voltage measurement
    #define PIN_POT_Y       4   // ADC input for Y-axis scaling
    #define PIN_POT_X       3   // ADC input for X-axis scaling
    #define PIN_BUTTON      7   // Digital input for mode button
    #define PIN_TPI         20  // Test Point Input control

    // I2C Pin Definitions
    #define SDA_PIN 8   // Default I2C SDA
    #define SCL_PIN 9   // Default I2C SCL
    
    // E-ink display pins
    #define EPD_DC      5
    #define EPD_CS      6
    #define SRAM_CS     9  
    #define EPD_RESET   -1
    #define EPD_BUSY    -1

    // SPI Pins for E-ink
    #define SCLK        8
    #define MISO        4
    #define MOSI        3
#endif

// Verify that a board is selected
#if !defined(BOARD_ESP32S3_MINI) && !defined(BOARD_ESP32C3_SUPER_MINI)
    #error "Please select a board by uncommenting one of the board definitions at the top of board_config.h"
#endif

#endif // BOARD_CONFIG_H

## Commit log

2025-02-01 Initial commit: I-V curve analyzer with ESP32-S3 Mini
2025-02-01 Document voltage divider and update block diagram
2025-02-01 Update I-V curve plot to show power curve and MPP correctly
2025-02-01 Adjust y-axis scales to better position power curve
2025-02-01 Add voltage divider information to documentation
2025-02-02 docs: reorganize documentation and add prototype photos
    - Move HARDWARE.md to hardware/ directory
    - Add prototype photos in images/prototype/
    - Fix markdown formatting in README.md
    - Update documentation structure and links
    [ADG706BRUZ-REEL7.step, I-V-CurvePCB.kicad_pcb, I-V-CurvePCB.kicad_sch]
2025-02-02 docs: add hardware README with PCB design documentation
    - Add detailed overview of PCB design improvements
    - Document ADG706 multiplexer upgrade
    - Add file structure and component documentation
    - Include links to all relevant files
2025-02-02 Improve code documentation: Add comprehensive comments for hardware setup, pin definitions, measurements, and display functions. Restore I2C pin definitions.
2025-02-11 new mux
    [ADG706BRUZ-REEL7.step, I-V-CurvePCB.kicad_pcb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]
2025-02-12 Update firmware and hardware: - Add voltage scaling and MPP calculations - Improve web interface display units - Update KiCad files for ADG706 design - Update .gitignore for KiCad projects
    [MUX-ADG706.kicad_pcb, MUX-ADG706_copy.kicad_sch]
2025-02-12 Add board configuration system: - Create board_config.h for ESP32-S3 Mini and ESP32-C3 Super Mini - Update pin assignments for both boards - Move configuration to src directory - Update hardware docu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
2025-02-12 Include gerber files for open hardware manufacturing
    [MUX-ADG706-B_Cu.gbr, MUX-ADG706-B_Mask.gbr, MUX-ADG706-B_Paste.gbr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]
2025-02-12 Remove KiCad backup files from git tracking (kept locally)
2025-02-13 Enhanced web interface and OLED display: - Improved measurement display styling - Fixed units (V, mA, mW) - Removed power axis grid lines - Added screenshot
    [IVserver.cpp, board_config.h, main.cpp]
2025-02-13 ui: Improve graph display - Reduce container width to 600px - Connect power curve to origin for complete visualization
2025-02-17 Added resistor correction factor to improve current measurements
    [main.cpp]
2025-02-17 Improvements: voltage divider fix, power curve display, timing adjustments
    - Fix voltage reading by multiplying by 2 for voltage divider
    - Use dashed lines for previous power curve only
    - Fix array bounds in power curve drawing loops
    - Adjust averaging and timing parameters
    - Improve OLED display formatting for MPP values
    [main.cpp]
2025-02-17 docs: add e-ink display documentation and button functionality to README
2025-03-01 Fix MPP display: Use voltage and current values at maximum power point instead of absolute maximums
    [board_config.h, main.cpp]
2025-03-02 minor fixed on the diplay and label axes
    [main.cpp]
2025-08-15 Add Max/MSP integration and enhance IV server API
    ✨ New Features:
    - Add Max/MSP integration folder with patches for real-time IV curve visualization
    - New text-based API endpoints for better data export:
    • /voltage.txt - CSV voltage measurements
    • /current.txt - CSV current measurements
    • /power.txt - CSV power calculations
    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
2025-08-15 Fix Max/MSP JavaScript Rs calculation and outlet order
    - Fix abnormal Rs calculation (was showing -7420Ω, now shows reasonable values)
    - Correct outlet order to match specification:
    • Outlet 0: F_ohmic [FF, Vmpp/Voc, Impp/Isc, Rs, Rsh, curvature, area]
    • Outlet 1: F_dimless [FF, Vmpp/Voc, Impp/Isc, rs, rsh, curvature, area]
    • Outlet 2: basics [Voc, Isc, Vmpp, Impp]
    • Outlet 3: norm_64_curve [Vn0, In0, Vn1, In1, ...]
    - Add diagnostic output for Rs calculation debugging
    - Improve data point selection for more stable slope calculations
    - Add validation to reject unreasonable Rs/Rsh values
    - Update Max patch to work with corrected JS object
    These fixes ensure accurate solar cel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
